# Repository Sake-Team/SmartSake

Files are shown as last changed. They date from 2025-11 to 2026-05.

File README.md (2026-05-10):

# SmartSake

Temperature monitoring and fan control system for koji fermentation, built on a Raspberry Pi 4B.

Reads six MAX31850K thermocouples, an SHT30 humidity sensor, and up to four HX711 load cells. Controls six relay-switched fans to hold temperature curves. Serves a real-time web dashboard over the local network.

<!-- ## Screenshots
Drop PNGs into `images/` and uncomment:
![Dashboard](images/dashboard.png)
![Mobile View](images/mobile.png)
![Curve Builder](images/curves.png)
-->

## About the Project

SmartSake is the controls and instrumentation half of a senior capstone project for the **University of Kentucky Biosystems & Agricultural Engineering** department (BAE 402/403, Fall 2025 – Spring 2026). The mechanical half — the koji table and load cell housings — is documented in `hardware/` and `docs/`.

**Team:** Benjamin Lin, Anastasia Myers, Makenna Hull, Natalie Cupples
**Advisor:** Dr. Alicia Modenbach

For background on the design — problem definition, constraints, alternatives considered, and economic justification — see [`docs/design-report.pdf`](docs/design-report.pdf).

## Safety

This system controls mains-voltage equipment near food-contact surfaces. Before powering anything on:

- **Electrical:** All 120 VAC wiring (relay → fan power) must be enclosed and follow [`docs/schematics/power-schematic.pdf`](docs/schematics/power-schematic.pdf). Do not energize with the relay board exposed. The Pi must be on a separate 5V supply, never tapped from the fan rail.
- **Thermal:** Fans run hot under sustained load. The auto fan-control loop has no upper bound — a misconfigured `tolerance_c` of 0 will keep fans on indefinitely. Always set a sane tolerance (1–2 °C) and check the dashboard during the first hour of every new run.
- **Food contact:** Only the load cell housing surface and the koji table top are food-contact. Use food-safe PETG or food-safe-coated PLA for the [STL parts](hardware/stl/), and sanitize between runs.
- **Crash recovery:** systemd `Restart=on-failure` brings the server back if it dies; the SIGTERM handler drives every fan relay HIGH (= OFF on active-LOW) before exit, so a clean restart leaves no fan stranded on. A hard kill (`SIGKILL`, power loss) bypasses the handler — relays hold their last state.
- **systemd watchdog:** the unit ships with `WatchdogSec=60`; `WriteSensors.py` calls `sd_notify("WATCHDOG=1")` once per sensor tick (~10 s) so a frozen loop is caught and restarted. To temporarily disable the watchdog, drop in `/etc/systemd/system/smartsake.service.d/no-watchdog.conf` with `[Service]\nWatchdogSec=0`, then `systemctl daemon-reload && systemctl restart smartsake`.
- **Hard cutoff:** The dashboard no longer ships an in-page emergency-stop button. To force all fans OFF, kill power at the relay board, or POST to `/api/runs/<id>/emergency-stop` directly (the route still exists server-side).

---

## Daily Operations

The cheat sheet for running SmartSake day-to-day. Detailed background lives in sections 3–4.

### Service control

| Command | Effect |
|---|---|
| `./restart.sh` | Bring up the SmartSake WiFi AP (static IP `192.168.50.1` on `wlan0`, sudo), ensure Tailscale is connected, then restart the server. Default behavior. |
| `./restart.sh --status` | Show whether the server is running |
| `./restart.sh --logs` | Tail the live server log |
| `./restart.sh --ap` | Same as default — explicitly bring up the AP and restart the server (sudo) |
| `./restart.sh --no-ap` | Tear down AP, return to home WiFi (sudo), then restart |
| `./restart.sh --skip-ap` | Restart server without touching network state (use when AP is already up or on dev boxes) |
| `./scripts/ap-mode.sh status` | Report current AP mode without changing anything |
| `sudo systemctl restart smartsake` | Same as `./restart.sh` under systemd |
| `journalctl -u smartsake -f` | Live service journal |

### Where to point the browser

| Mode | URL |
|---|---|
| Home WiFi (normal) | `http://<pi-ip>:8080` — find with `hostname -I` on the Pi |
| AP mode | `http://192.168.50.1:8080` after joining SSID `SmartSake` (default password `kojitable`) |
| Mobile dashboard (any mode) | `<base>/mobile.html` |

### Web pages

| Page | Purpose |
|---|---|
| `/home.html` (default) | New Run, active run resume, previous-runs list, **System Health** card |
| `/dashboard.html?run=<id>&mode=live` | Live monitoring + zone control + bulk setpoint editor |
| `/dashboard.html?run=<id>&mode=replay` | Historical chart playback |
| `/calibration.html` | Probe→zone mapping, TC 2-point cal, load-cell cal (Tare / Calibrate / Calibrate All / Multi-Point / **Apply Manual**) |
| `/curves.html` | Reference temperature curve builder |
| `/mobile.html` | Compact view for phones/tablets |
| `/room-history.html` | Long-window environmental history (lives across runs) |
| `/summary.html?run=<id>` | Per-run digest |
| `/history.html?run=<id>` | Run metadata + tabular detail |

### Starting / running / ending a run

1. **Start** — Home page → enter a run name → optionally pick a reference curve → **Start**. Lands on the live dashboard.
2. **Set targets** — Click **Setpoints / Update** on the dashboard → enter setpoint + tolerance per zone → **Apply All**. Or click any zone to edit one zone's setpoint inline.
3. **Manual fan override** — Open a zone's detail card → segmented pill: `Auto | Off · 1hr | Off | On · 1hr | On`. The 1-hour options auto-revert to Auto.
4. **Notes** — type into the dashboard notes box; saved to localStorage and appended to every CSV row.
5. **End run** — Dashboard **End Run** button. CSV downloads automatically. localStorage cleared (no phantom run on next visit).
6. **Crash recovery** — if the dashboard tab dies mid-run, reopening it silently auto-exports the recovered samples to CSV.

### Calibration (load cells)

1. **Calibrate All (centered load)** — empty the table → **Tare All**. Place a known total weight at the center → enter total kg → **Calibrate All** (splits weight evenly across the 4 cells).
2. **Single cell** — per-row **Tare** (with that cell empty) then **Calibrate** with a known weight on just that cell.
3. **Multi-Point Cal** — open the inline panel for one cell → record zero, then add successive known weights → live raw + computed-kg charts show the fit.
4. **Apply Manual** — type new values directly into the per-row Tare or Factor cells → click **Apply Manual** for that row to nudge without re-loading weights.

### Settings (gear icon, top-right of any page)

- Theme presets (dark, ocean, forest, sakura, etc.)
- **Display Units** — kg/lbs and °C/°F. Flips the dashboard, mobile, room-history, summary, and calibration screens in real time.
- Run Settings (dashboard only) — temperature-deviation thresholds, alert behavior.

### Diagnostics

| Check | How |
|---|---|
| Service alive? | `./restart.sh --status` or look at home page **System Health** card |
| Fan acting weird? | `journalctl -u smartsake -f \| grep '\[fan'` — auto loop logs every transition |
| Sensor errors? | Home page **System Health** → Sensor loop status. Or `cat /run/smartsake/sensor_status.json` |
| Disk getting tight? | Home page **System Health** → Disk free. Threshold warnings start at 100 MB. |
| Multiple "active" runs? | Home page **System Health** → Active runs (should be 0 or 1). The DB now auto-supersedes leftovers on next run start. |
| Smoke-test the fan logic | `python3 test_fan_state.py` — exercises the override / hysteresis / shutdown paths |
| Deeper debug playbook | [`DEBUG.md`](DEBUG.md) — symptom → cause trees for auto fan switching and load cell calibration |

---

## Quickstart

If your Pi is wired and SSH-able:

```bash
git clone https://github.com/Sake-Team/SmartSake.git
cd SmartSake
git checkout ClaudeAgents
sudo bash scripts/onboarding.sh     # Phase 1: install packages, enable overlays
# --- Pi reboots here ---
sudo bash scripts/onboarding.sh     # Phase 2: map thermocouples, calibrate, start service
```

The setup wizard auto-detects which phase to run. After Phase 2, open `http://<pi-ip>:8080` and start a run.

For sensor setup without the full onboarding (e.g., after replacing a probe):

```bash
./setup.sh              # map thermocouples, verify sensors, start service
./setup.sh --remap      # re-run TC identification only
./setup.sh --verify     # check all sensors without starting
./setup.sh --status     # show sensor + service state
```

For manual setup or troubleshooting individual steps, see the full instructions below.

---

## Table of Contents

0. [Daily Operations (cheat sheet)](#daily-operations)
1. [Hardware Setup](#1-hardware-setup)
2. [Software Installation](#2-software-installation)
3. [Running SmartSake](#3-running-smartsake)
4. [Using the Dashboard](#4-using-the-dashboard)
5. [Hardware Files](#5-hardware-files)
6. [Documentation](#6-documentation)
7. [Troubleshooting](#7-troubleshooting)
8. [API Reference](#8-api-reference)
9. [Glossary](#9-glossary)
10. [Contributing](#10-contributing)
11. [License](#11-license)
12. [Acknowledgments](#12-acknowledgments)

---

## 1. Hardware Setup

### Parts List

Quick reference — for the full Bill of Materials with vendors, part numbers, and costs see [`BOM.md`](BOM.md).

| Component | Model | Qty |
|---|---|---|
| Single-board computer | Raspberry Pi 4B | 1 |
| Thermocouple amplifier | MAX31850K (1-Wire) | 6 |
| Humidity/temp sensor | SHT30 (I2C) | 1 |
| Relay board | SunFounder TS0012 (active-LOW, 8-ch) | 1 |
| Load cell amplifier | HX711 | 1-4 |
| Fans | 12V DC (one per zone) | up to 6 |

### GPIO Pin Map (BCM numbering)

```
Pin  2 ── SHT30 SDA (I2C)
Pin  3 ── SHT30 SCL (I2C)
Pin  4 ── 1-Wire data bus (all six MAX31850K)
Pin  5 ── HX711 Scale 1 DAT
Pin  6 ── HX711 Scale 1 CLK
Pin 12 ── HX711 Scale 2 DAT
Pin 15 ── HX711 Scale 2 CLK   (UART RXD0 — disable serial console if used)
Pin 16 ── HX711 Scale 3 DAT
Pin 17 ── Relay CH5 → Fan Zone 5
Pin 19 ── HX711 Scale 3 CLK
Pin 20 ── HX711 Scale 4 DAT
Pin 21 ── HX711 Scale 4 CLK
Pin 22 ── Relay CH4 → Fan Zone 4
Pin 23 ── Relay CH3 → Fan Zone 3
Pin 24 ── Relay CH2 → Fan Zone 2
Pin 25 ── Relay CH1 → Fan Zone 1
Pin 27 ── Relay CH6 → Fan Zone 6
```

> **Reserved pins:** 2/3 (I2C), 4 (1-Wire), 5/6/12/15/16/19/20/21 (HX711). Do not use these for relays.

### Relay Wiring (Active-LOW)

The SunFounder TS0012 is active-LOW:

- **GPIO LOW** = relay coil energized = fan **ON**
- **GPIO HIGH** = relay coil de-energized = fan **OFF**

All relay pins initialize HIGH at boot so fans start OFF.

### 1-Wire Bus (Thermocouples)

All six MAX31850K probes share a single 1-Wire bus on GPIO 4. Each probe has a unique device ID starting with `3b-` and appears at:

```
/sys/bus/w1/devices/3b-XXXXXXXXXXXXX/w1_slave
```

Enable the 1-Wire overlay in `/boot/config.txt`:

```
dtoverlay=w1-gpio,gpiopin=4
```

After wiring, run the probe identification script to assign each physical probe to a zone (1-6):

```bash
python3 scripts/identify_tcs.py
```

This creates `tc_zone_map.json` — the sensor loop will not start until all six zones are mapped.

### SHT30 (I2C)

The SHT30/SHT31 connects to the default I2C bus (pins 2/3). Enable I2C in `raspi-config` if not already on. No additional configuration needed.

### HX711 Load Cells

Scale 1 uses GPIO 5 (DAT) and GPIO 6 (CLK). Scales 2-4 are defined in `scale_config.json` but not wired by default. To calibrate:

```bash
python3 load_cell_hx711.py --calibrate --scale 1
```

To re-tare without full calibration:

```bash
python3 load_cell_hx711.py --tare --scale 1
```

---

## 2. Software Installation

### Prerequisites

```bash
# System packages
sudo apt update
sudo apt install python3 python3-pip git

# Python dependencies
pip3 install flask gunicorn

# Pi hardware libraries
pip3 install RPi.GPIO
pip3 install adafruit-blinka adafruit-circuitpython-sht31d
```

### Clone the Repo

```bash
cd ~
git clone https://github.com/Sake-Team/SmartSake.git
cd SmartSake
git checkout ClaudeAgents
```

### Configuration Files

Three JSON files control hardware mapping. They live in the project root:

**`tc_zone_map.json`** — Thermocouple-to-zone assignment (generated by `scripts/identify_tcs.py`):

```json
{
  "3b-000000000001": 1,
  "3b-000000000002": 2,
  "3b-000000000003": 3,
  "3b-000000000004": 4,
  "3b-000000000005": 5,
  "3b-000000000006": 6
}
```

**`zone_config.json`** — Per-zone temperature tolerance and calibration:

```json
{
  "default": { "tolerance_c": 1.0 },
  "zone1":   { "tolerance_c": 1.0, "setpoint_c": 32.0 },
  "zone2":   { "tolerance_c": 1.5 }
}
```

Optional per-zone fields: `setpoint_c`, `offset_c` (legacy single-point cal), `cal_slope` + `cal_intercept` (two-point cal).

**`scale_config.json`** — Load cell calibration and SHT30 offset:

```json
{
  "sensors": {
    "sht30_temp_offset_c": 0.0
  },
  "scales": {
    "1": {
      "dat_pin": 5,
      "clk_pin": 6,
      "tare_offset": 4166,
      "calibration_factor": 8000,
      "units": "kg",
      "label": "Scale 1"
    }
  }
}
```

### Install systemd Services

For production use on the Pi, install the systemd units so SmartSake starts on boot and auto-restarts on failure:

```bash
sudo bash systemd/install.sh
```

This installs and enables:

| Service | Purpose |
|---|---|
| `smartsake.service` | Flask server + sensor loop (port 8080) |
| `smartsake-sensors.service` | Standalone sensor loop (for multi-worker setups, conflicts with above) |
| `smartsake-backup.timer` | Database backup every 6 hours |

The main service runs as user `kojitable` with resource limits:

- **Memory:** 256 MB max
- **CPU:** 80% quota
- **Watchdog:** 60s (kills hung process)
- **tmpfs:** `/run/smartsake/` for volatile JSON files (protects SD card). Holds `sensor_latest.json`, `fan_state.json`, `sensor_status.json`, and `no_run_overrides.json`.

### Database

SQLite database (`smartsake.db`) is created automatically on first run. No manual setup needed.

---

## 3. Running SmartSake

### Start / Stop / Restart

The canonical way to manage SmartSake is through `restart.sh`, which detects whether systemd is installed and acts accordingly:

```bash
# Start or restart
./restart.sh

# Check status
./restart.sh --status

# Tail live logs
./restart.sh --logs
```

If systemd is installed, these map to:

```bash
sudo systemctl restart smartsake
sudo systemctl status smartsake
journalctl -u smartsake -f
```

If systemd is not installed (development mode), `restart.sh` runs `server.py` directly with `nohup`, logging to `server.log`.

### First Run

1. Wire all hardware and enable 1-Wire + I2C in `raspi-config`
2. Run `python3 scripts/identify_tcs.py` to create `tc_zone_map.json`
3. Run `python3 load_cell_hx711.py --calibrate --scale 1` (if using a scale)
4. Install services: `sudo bash systemd/install.sh`
5. Open `http://<pi-ip>:8080` in a browser

### Stopping the Server

```bash
# With systemd
sudo systemctl stop smartsake

# Without systemd (dev mode)
pkill -f "python.*server.py"
```

### Updating

Pull the latest code and restart:

```bash
cd ~/SmartSake
git pull
./restart.sh
```

### Standalone WiFi Access Point Mode

The Pi self-hosts a local LAN. `./restart.sh` brings the SmartSake WiFi AP
up by default (no flag needed) on `wlan0` with the static IP defined in
`scripts/ap-config.env` (`192.168.50.1` by default). Mobile devices join
SSID `SmartSake` and reach the dashboard at `http://192.168.50.1:8080`.

```bash
# Default: bring up the AP, assign 192.168.50.1, then start the server
sudo ./restart.sh

# Explicit alias of the default
sudo ./restart.sh --ap

# Tear down the AP, return to home WiFi, restart the server
sudo ./restart.sh --no-ap

# Restart the server WITHOUT touching network state (server only)
./restart.sh --skip-ap

# Or call the helper directly
sudo ./scripts/ap-mode.sh start
sudo ./scripts/ap-mode.sh stop
./scripts/ap-mode.sh status
```

Defaults: SSID `SmartSake`, password `kojitable`, **static IP `192.168.50.1`**,
DHCP pool `192.168.50.50`–`.150`. Edit `scripts/ap-config.env` to change. The
static IP is reapplied on every `./restart.sh` via `ip addr add` against
`wlan0`, so the Pi is always reachable at the same address while the AP is up.

**Prerequisites:** `sudo apt install hostapd dnsmasq`.

**Best-effort start:** if `restart.sh` runs on a box with no `wlan0`, no sudo,
or missing `hostapd`/`dnsmasq`, the AP step warns and is skipped — the server
still starts. Use `--skip-ap` to suppress the attempt entirely on dev boxes.

**Reversibility:** `--no-ap` removes the AP configs (`/etc/hostapd/smartsake.conf`,
`/etc/dnsmasq.d/smartsake-ap.conf`), restarts NetworkManager / wpa_supplicant,
and the Pi reconnects to home WiFi.

**Recommendation for first try:** keep a wired ethernet cable connected so SSH
remains reachable if anything goes sideways.

### Remote access via Tailscale

The Pi runs `tailscaled` as an enabled systemd service, so it auto-starts on
boot and reconnects automatically to the tailnet (no flag, no login required
after the initial `tailscale up`). On every `./restart.sh` an idempotent
`ensure_tailscale_up` step verifies the connection: if `tailscale ip -4`
already returns an address it's a no-op, otherwise it runs `sudo tailscale up`.
A missing binary or auth failure is warned and does not abort the script.

```bash
# Initial one-time auth (prints a URL to open in a browser)
sudo tailscale up

# Verify
tailscale status
tailscale ip -4
```

Once authenticated, this Pi is reachable from any other tailnet device by its
tailnet IP (or MagicDNS hostname) — useful for working off-site without
exposing port 8080 to the public internet. Install Tailscale on your laptop,
sign in to the same account, then `ssh kojitable@<tailnet-ip>` or browse to
`http://<tailnet-ip>:8080`.

### Development Mode (Windows/Mac)

A mock server is included for UI development without Pi hardware:

```bash
pip install flask
python archive/mock_server.py
# Opens at http://localhost:8080 with simulated sensor data
```

The mock serves the real HTML/CSS/JS from the project root and stubs every API
endpoint the dashboard, calibration page, curves page, and zone pages call —
including `/api/sensor-status`, `/api/tc-probes`, `/api/tc-zone-map`,
`/api/tc-calibration/<zone>/...`, `/api/scale-config[/<id>/...]`,
`/api/runs/<id>/summary`, `/api/reference-curves/generate[-from-csv]`,
`/api/runs/<id>/emergency-stop`, `/api/fans/<zone>`, and `/api/prune`.

All hardware imports degrade gracefully — `RPi.GPIO`, `adafruit_sht31d`, and HX711 log warnings and run as no-ops when unavailable.

---

## 4. Using the Dashboard

### Accessing SmartSake

Once running, open a browser to:

```
http://<pi-ip-address>:8080
```

Find the Pi's IP with `hostname -I` on the Pi, or check your router's device list.

### Pages

| Page | URL | Purpose |
|---|---|---|
| Home | `/` | Start/resume runs, view history |
| Dashboard | `/dashboard.html?run=N&mode=live` | Real-time temp, fan, and weight monitoring |
| Mobile | `/mobile.html` | Lightweight phone/tablet view |
| Calibration | `/calibration.html` | TC offset and load cell calibration |
| Curve Builder | `/curves.html` | Create/edit temperature reference curves |
| History | `/history.html?run=N` | Detailed run data table |
| Summary | `/summary.html?run=N` | Hourly temperature statistics |
| Room History | `/room-history.html` | Ambient environment over time |

### Home Page

The landing page shows:

- **Active run** — if a batch is in progress, with a "Resume" button to jump to the live dashboard
- **New Run** — name a batch and optionally attach a reference temperature curve
- **Tools** — links to Curve Builder, Calibration, Room History, and Mobile View
- **System Health** — at-a-glance Pi status: active-runs count (should be 0–1; >1 surfaces a leak), sensor-loop status, last sample age, free disk, and any active fan overrides (in-run + no-run with mode and time-to-expiry). Polls `/api/system-health` every 15 s while the tab is visible; pauses when hidden.
- **Previous Runs** — all completed/crashed batches with View, Summary, Details, Lock, and Delete actions

### Dashboard (TV / Desktop)

The main dashboard is designed for a wall-mounted display. It shows:

- **Six zone cards** — current temperature, fan state (ON/OFF badge), and deviation from target
- **Temperature chart** — live line graph updated every 10 seconds
- **Fan state indicators** — mode (limit/manual/rule), setpoint, trigger point, alarm level
- **Weight chart** — load cell readings updated every 30 seconds
- **Humidity/ambient** — SHT30 environment readings
- **Zone controls** — click any zone card to open fan overrides, rules, notes, and calibration
- **Update Setpoints card** — opens a blanket-only modal: enter one setpoint and/or one tolerance, click Apply, and the values are written to every zone in a single atomic POST to `/api/zone-config/all` (RLock-guarded on the server). Per-zone edits live on each zone card's existing detail modal
- **Display units** — open the gear (Settings) modal to switch weight between **lbs / kg** and temperature between **°C / °F**. Both preferences persist in `localStorage` (`sakeWeightUnit`, `sakeTempUnit`); changes apply live to every dashboard chart, stat card, zone card, and zone-detail modal — and propagate (via the `sake-units-changed` event plus a cross-tab `storage` listener) to **`mobile.html`**, **`room-history.html`**, and **`summary.html`**. Internally the backend always stores Celsius — `°F` inputs are converted on send (and tolerance, being a delta, is divided by `9/5`).

**Fan control modes:**

| Mode | How it works |
|---|---|
| Auto (limit) | Fans turn on when temp exceeds setpoint + tolerance, off when temp drops below setpoint |
| On / Off (untimed) | Force a zone's fan ON or OFF until you press Auto. Persists across service restarts (cleared on full reboot). |
| On · 1hr / Off · 1hr | Same as above but auto-expires after 60 minutes, returning the zone to Auto. |
| Rules | Time-window or threshold-based triggers (configured per-run) |

**Override persistence:**

- **Active run:** overrides live in the SQLite `fan_overrides` table — survive any restart, expire on `expires_at`.
- **No active run:** overrides live in `/run/smartsake/no_run_overrides.json` (volatile dir) — survive `smartsake.service` restarts (watchdog, deploys, crashes), but cleared on a full reboot for safety.
- Starting a new run wipes any no-run overrides (the run owns its own override table).

### Mobile Dashboard (iPhone / iPad)

Navigate to `/mobile.html` or tap "Mobile View" from the home page.

Optimized for phones (375px and up):

- **2-column grid** of zone cards with large temperature numbers
- **Fan ON/OFF badges** per zone (green/gray)
- **Alarm states** — amber border for warnings, pulsing red for critical deviations
- **Environment bar** — humidity and ambient temp
- **Weight summary** — shown when a scale is active
- **Connection-lost banner** — appears after 3 failed fetches
- **Stale-data indicator** — timestamp turns amber if data is older than 60 seconds

The mobile page is read-only (monitoring only). For fan overrides and zone configuration, use the full dashboard.

To add SmartSake to your iPhone home screen as an app:

1. Open `http://<pi-ip>:8080/mobile.html` in Safari
2. Tap the Share button → "Add to Home Screen"
3. It will launch full-screen without Safari's address bar

### Calibration Page

`/calibration.html` (linked from the home page) covers thermocouple offsets, probe-to-zone mapping, and load cell calibration. The thermocouple workflows (`2-Point Cal`, `Quick Cal`) and the probe mapping panel are documented inline on the page.

#### Probe → Zone Heat-Detect (web equivalent of `identify_tcs.py`)

The **Probe → Zone Mapping** panel now mirrors the CLI's heat-and-identify flow so the mapping can be (re)built without dropping to a shell:

1. Pick the zone you want to identify from the **Detect zone** dropdown.
2. Click **Capture Baseline** — the current temperature of every probe on the 1-Wire bus is snapshotted; the **Δ since baseline** column resets to `+0.00`.
3. Physically heat the probe you want for that zone (skin contact, hot-water bath, etc.) for ~15 s. The Δ column updates every poll (~3 s); rows that climb ≥ 2 °C above baseline are highlighted in green.
4. Click **Detect (after heating)** — the probe with the largest rise (excluding probes already manually assigned to other zones) is auto-assigned to the chosen zone, and the Detect dropdown advances to the next unassigned zone.
5. Repeat for each remaining zone, then click **Save Mapping**. The mapping is persisted to `tc_zone_map.json` and the sensor loop picks it up within ~10 s.

The 2 °C rise threshold mirrors `RISE_THRESHOLD_C` in `scripts/identify_tcs.py`. Below-threshold detections are rejected with a status message ("heat longer and click Detect again") rather than silently misassigning. **Clear Baseline** discards the snapshot if you want to redo the protocol. Manual dropdown selections are preserved across the 3-second poll — the table now diff-renders, so in-progress edits aren't wiped before you save.

#### Calibrate All (Centered Load)

Above the per-scale table, a **Calibrate All (centered load)** panel handles all 4 cells in two clicks. Step 1: empty the table and click **Tare All** — every wired scale tares in parallel. Step 2: place a known weight at the **center** of the table, enter the **total mass in kg**, and click **Calibrate All**. The total is divided equally across the wired cells (`total / 4`, or `total / N` if fewer than 4 are wired) and pushed to each scale's `known_weight_kg`. Unwired scales are skipped automatically. The per-scale Tare / Calibrate / Multi-Point Cal buttons in the table below remain available for individual cells.

#### Multi-Point Cal (Load Cells)

For higher accuracy across a wide load range (e.g. 0–9 kg of rice), use the **Multi-Point Cal** workflow on the calibration page:

1. Open `/calibration.html` and find the scale row in the **Load Cells** panel.
2. Click **Multi-Point Cal** — an inline panel expands below the row.
3. **Step 1 — Record Zero**: place the table and any fixed load you want zeroed (housings, lids, empty trays). Click **Record Zero (with table loaded)**. The current raw reading is declared as `0 g`. You don't need to know the mass of the fixture.
4. **Step 2+ — Add Known Weight**: place a known mass on the scale, type its weight in grams (or click a rice-bag preset: 2000 g / 4000 g / 5000 g / 9000 g), optionally add a label, then click **Record Point**. Repeat for as many reference weights as you want — the more spread, the better the fit.
5. The recorded points table shows each point's label, weight, raw ADC reading, and delta from the previous raw. Use **Remove** to drop a single point, or **Clear All Points** to start over.
6. Two side-by-side live charts update once a second while the panel is open:
   - **Left (Raw ADC)**: rolling 60-sample window of the raw integer reading. Useful for spotting noise, drift, or wiring issues.
   - **Right (Computed weight, kg)**: the same window converted to kg using the **currently saved** calibration. Horizontal dashed reference lines mark each recorded `weight_g / 1000`, so you can see how close the live reading lands to each known point.
7. Below the right chart, a **residuals readout** shows, for each recorded point, the live error in grams (`live reads X g, error ±Y g`).
8. Click **Done** to close the panel — the fast 1 s polling loop is torn down automatically (and also pauses when the browser tab is hidden).

The backend auto-derives `tare_offset` and `calibration_factor` from the min-weight and max-weight points whenever 2 or more points are present, so the running scale picks up the multi-point cal immediately — no service restart needed. The single-point **Tare** and **Calibrate** buttons remain available as a quick-cal alternative.

### Polling Intervals

| Data | Backend interval | Frontend poll |
|---|---|---|
| Temperature (TC) | 10s | 10s |
| Humidity (SHT30) | 10s | 10s |
| Fan relay control | 10s | 10s |
| Weight (HX711) | 30s | 30s |
| Stage markers | on change | 30s |

Front-end pollers (`fetchAndApply`, `fetchFanState`) carry an in-flight reentrancy guard, so a slow Pi will skip a tick instead of stacking parallel requests.

### Accessibility

The dashboard is the primary operator surface and aims for WCAG 2.1 AA on the controls that matter most for safe operation:

- All icon-only buttons (settings gear, elapsed/clock toggle) have explicit `aria-label`s.
- The fan-mode segmented control is a `role="group"` with `aria-pressed` mirroring the visual `--active` state, so screen readers announce the current selection.
- The connection-lost banner is an `role="alert" aria-live="assertive"` region; sensor poll failures are announced.
- All four metric canvases (temperature, humidity, fans, weight) have descriptive `aria-label`s.
- Keyboard focus on every primary control surface (fan-mode segments, time-window buttons, settings) shows a 2 px outline via `:focus-visible` — outlines are painted outside the box, so layout doesn't shift.
- `prefers-reduced-motion: reduce` disables transitions on interactive controls.

---

## File Structure

```
SmartSake/
├── server.py              # Flask API server (starts sensor loop as background thread)
├── WriteSensors.py        # Sensor collection loop (standalone or via server.py)
├── db.py                  # SQLite database layer
├── fan_gpio.py            # GPIO relay abstraction
├── sensors.py             # 1-Wire and SHT30 helpers
├── load_cell_hx711.py     # HX711 ADC driver and calibration CLI
├── home.html              # Landing page
├── dashboard.html         # Main monitoring dashboard
├── dashboard-phase2.js    # Stage markers + weight analytics overlay
├── mobile.html            # Mobile-optimized dashboard
├── calibration.html       # TC and scale calibration UI
├── curves.html            # Reference curve builder
├── history.html           # Run detail table
├── summary.html           # Hourly stats for completed runs
├── room-history.html      # Ambient environment history
├── styles.css             # Shared theme and component styles
├── customize.js           # Theme customization (light/dark)
├── restart.sh             # Start/restart/status/logs helper
├── requirements.txt       # Python dependencies
├── tc_zone_map.json       # Probe-to-zone mapping (generated)
├── zone_config.json       # Per-zone tolerance and calibration
├── scale_config.json      # Load cell config and SHT30 offset
├── smartsake.db           # SQLite database (auto-created)
├── sensor_data.csv        # Rolling CSV log (~24 hrs)
├── archive/
│   └── mock_server.py    # Local UI preview server (no Pi required)
├── scripts/
│   └── identify_tcs.py    # Interactive probe identification
├── systemd/
│   ├── smartsake.service          # Main service unit
│   ├── smartsake-sensors.service  # Standalone sensor unit
│   ├── smartsake-backup.service   # DB backup (oneshot)
│   ├── smartsake-backup.timer     # Backup schedule (every 6h)
│   └── install.sh                 # Service installer
├── images/
│   └── VoidSakeLogo.jpg   # Logo
├── hardware/
│   ├── bill-of-materials.xlsx
│   ├── cad/
│   │   ├── sake-table-drawing.pdf
│   │   ├── sake-table-exploded.png
│   │   └── load-cell-housing-drawing.pdf
│   └── stl/
│       ├── load-cell-housing.stl
│       └── load-cell-housing-lid.stl
└── docs/
    ├── design-report.pdf
    ├── standards-memo.pdf
    ├── brewing-flow-chart.png
    └── schematics/
        ├── koji-room-layout.png
        ├── power-schematic.pdf
        ├── wiring-schematic.pdf
        ├── signal-schematic.svg
        └── smartsake-wiring.json   # EasyEDA source (LV signal + 120 V power, 2 sheets)
```

---

## 5. Hardware Files

### Bill of Materials

[`hardware/bill-of-materials.xlsx`](hardware/bill-of-materials.xlsx) — full parts list with vendors, part numbers, quantities, and unit costs (Spring 2026 revision).

### CAD Drawings

| File | Description |
|---|---|
| [`hardware/cad/sake-table-drawing.pdf`](hardware/cad/sake-table-drawing.pdf) | Dimensioned drawing of the koji table (v3) |
| [`hardware/cad/sake-table-exploded.png`](hardware/cad/sake-table-exploded.png) | Exploded assembly view |
| [`hardware/cad/load-cell-housing-drawing.pdf`](hardware/cad/load-cell-housing-drawing.pdf) | Load cell housing dimensioned drawing |

### 3D-Printable Parts (STL)

| File | Description | Notes |
|---|---|---|
| [`hardware/stl/load-cell-housing.stl`](hardware/stl/load-cell-housing.stl) | Load cell housing body (v3) | PLA or PETG, 0.2mm layer, 30% infill |
| [`hardware/stl/load-cell-housing-lid.stl`](hardware/stl/load-cell-housing-lid.stl) | Load cell housing lid | Same settings as body |

The native Fusion 360 file (`SakeTableCAD.f3z`) is not included due to size; contact the team if you need the editable source.

---

## 6. Documentation

| File | Description |
|---|---|
| [`docs/design-report.pdf`](docs/design-report.pdf) | Full design report — problem, alternatives, final design, economic justification |
| [`docs/standards-memo.pdf`](docs/standards-memo.pdf) | Applicable engineering standards (food safety, electrical, fabrication) |
| [`docs/brewing-flow-chart.png`](docs/brewing-flow-chart.png) | Sake brewing process flow chart |
| [`docs/schematics/koji-room-layout.png`](docs/schematics/koji-room-layout.png) | Koji room physical layout |
| [`docs/schematics/power-schematic.pdf`](docs/schematics/power-schematic.pdf) | Power distribution schematic |
| [`docs/schematics/wiring-schematic.pdf`](docs/schematics/wiring-schematic.pdf) | Full wiring schematic (Pi → relays → fans → sensors) |
| [`docs/schematics/signal-schematic.svg`](docs/schematics/signal-schematic.svg) | Signal-level schematic (1-Wire, I2C, GPIO) |
| [`docs/schematics/smartsake-wiring.json`](docs/schematics/smartsake-wiring.json) | Editable EasyEDA source — Sheet 1: LV signal wiring (Pi GPIO → MAX31850K × 6, SHT30, HX711 × 4, relay logic). Sheet 2: 120 VAC power wiring (separate Pi-supply outlet, relay-switched fans, always-on dehumidifier). Open in EasyEDA Std Edition via *File → Open → Local*. |

---

## 7. Troubleshooting

### Stability tests
All standalone — no pytest, no hardware required. Each prints PASS/FAIL with a coloured summary and exits non-zero if anything fails. Run individually:

- `python3 test_fan_state.py` — fan state machine: mocks `db` + `fan_gpio`, exercises override/hysteresis/run-transition paths.
- `python3 test_config_robustness.py` — JSON config loaders (`zone_config.json`, `scale_config.json`, `tc_zone_map.json`, `no_run_overrides.json`, and `server._read_json_cached`) under empty/truncated/trailing-comma/non-UTF8/wrong-type/extreme-value inputs. Verifies graceful degradation.
- `python3 test_db_safety.py` — SQLite layer: fresh init, idempotent re-init, `PRAGMA integrity_check` on corruption, `create_run` superseding leftover active runs, `end_run` closing open deviation events, schema migration paths, and threadlocal connection isolation. Uses temp DBs via `tempfile.NamedTemporaryFile` — never touches `smartsake.db`.
- `python3 test_input_fuzz.py` — Flask API endpoints (test_client, no port binding): empty bodies, malformed JSON, wrong types, extreme numerics (Infinity / NaN / 1e300), unicode, oversize strings, bogus path params. Verifies 4xx not 5xx.
- `python3 test_failure_injection.py` — failure-injection: monkey-patches `set_fan`, `insert_reading`, `read_temp_c`, `HX711.get_weight`, `read_sht30`, `_load_zone_config`, `_persist_no_run_overrides`, etc. to raise mid-tick. Verifies the sensor loop, fan-eval, HX711 thread, and watchdog all degrade gracefully (log + continue) rather than crashing.
- `python3 test_concurrency.py` — threading/race stress: mtime-cached config readers (`scale_config.json`, `zone_config.json`, server's `_read_json_cached`), SQLite thread-local pool isolation under 8×100 concurrent inserts, `_no_run_overrides_lock` set/clear/purge/expiry hammer, fan-state atomic-write rename safety, and concurrent `_write_scale_cfg` (Calibrate-All) lost-update detection. Mocks `RPi.GPIO`, uses `tempfile` so it never touches real config or `smartsake.db`.

### Dashboard won't load / can't reach Pi
- `ping <pi-ip>` — confirm the Pi is on the network
- On the Pi: `sudo ss -tlnp | grep 8080` — confirm something is listening
- `sudo systemctl status smartsake` — check for crash loops
- If the port is taken by a stale process: `pkill -f "python.*server.py"` then `./restart.sh`

### "Sensor loop will not start — tc_zone_map.json incomplete"
All six probes must be mapped before the loop runs. There is no auto-assignment.
```bash
python3 scripts/identify_tcs.py            # interactive — heat each probe in turn
python3 scripts/identify_tcs.py --check    # validate (no dupes, all 6 present)
sudo systemctl restart smartsake
```

### Probe shows N/A or wild jumps
- Check the 1-Wire bus on GPIO 4 — `ls /sys/bus/w1/devices/` should list six `3b-…` entries
- Loose probe wiring is the most common cause; reseat at the screw terminal
- Live monitor without writes: `python3 scripts/identify_tcs.py --monitor`

### Fan stuck ON or OFF
1. Check the dashboard zone card for an active manual override or rule — clear it
2. Verify relay logic is active-LOW (GPIO LOW = fan ON) — see `fan_gpio.py`
3. If a relay is mechanically stuck, hard-cycle the relay board's 5V supply
4. Hit `POST /api/runs/<id>/emergency-stop` (e.g. `curl -X POST http://<pi>:8080/api/runs/$RUN/emergency-stop`) — or pull power at the relay board — to force all fans OFF, then diagnose

### Fan stays ON after clicking Auto
Clearing a manual ON override now also resets the auto-loop hysteresis (`_fan_on=False`, `_fan_hold_counts=0`) so the next auto evaluation starts from a fresh "fan off" baseline. Previously the fan could stay on indefinitely if the actual temp was inside the deadband (setpoint < actual ≤ trigger) because hysteresis preserved the manual ON state. Auto now re-evaluates fresh and only turns the fan back on when actual truly exceeds the trigger. Same behavior applies when a timed override expires naturally.

### Scale reads zero or drifts
- Re-tare without recalibrating: `python3 load_cell_hx711.py --tare --scale N`
- Full calibration with a known weight: `python3 load_cell_hx711.py --calibrate --scale N`
- Confirm DAT/CLK pins in `scale_config.json` match the wiring (defaults: 5/6 for scale 1)
- HX711 is sensitive to vibration and temperature swings; mount it rigidly

### "Database is locked"
Another process is writing. Stop everything and restart cleanly:
```bash
sudo systemctl stop smartsake smartsake-sensors
sudo systemctl start smartsake
```
The `-sensors` standalone unit conflicts with the main service — only one of them should be active.

### Hot-reload not picking up config changes
The server uses an mtime check. If you edit `zone_config.json` over SMB or with an editor that writes atomically (replacing the file), mtime updates correctly. If you `cat >` the file, mtime may not change — `touch zone_config.json` to force.

---

## 8. API Reference

All endpoints are JSON unless noted. Base URL is `http://<pi-ip>:8080`.

### Health & status
| Method | Path | Purpose |
|---|---|---|
| GET | `/api/health` | Overall system health (sensor loop, DB, GPIO) |
| GET | `/api/system-health` | Aggregator for the home-page System Health card. Returns `{active_runs, sensor_status, last_sample_age_s, disk_free_mb, overrides[]}`. 5 s server-side cache. `sensor_status.status` is `"unknown"` when `/run/smartsake/sensor_status.json` does not yet exist (e.g. fresh boot before the sensor loop has written status), so callers can distinguish "loop never reported" from "loop says ok". |
| GET | `/api/sensor-status` | Sensor loop diagnostics, library availability, last-write age |
| GET | `/api/latest` | Latest TC + SHT30 + weight reading |
| GET | `/api/fan-state` | Latest fan state per zone (mode, setpoint, alarm) |

### Runs
| Method | Path | Purpose |
|---|---|---|
| GET | `/api/runs` | List all runs |
| GET | `/api/runs/active` | Currently active run (if any) |
| POST | `/api/runs` | Start a new run — body: `{name, target_curve_id?}` |
| GET | `/api/runs/<id>` | Get run metadata |
| POST | `/api/runs/<id>/end` | Mark run completed |
| DELETE | `/api/runs/<id>` | Delete run (unless locked) |
| POST | `/api/runs/<id>/pin` | Lock/unlock run from deletion |
| POST | `/api/prune` | Free disk by deleting oldest unlocked runs |
| GET | `/api/runs/<id>/readings` | Full reading history |
| GET | `/api/runs/<id>/latest` | Latest reading for this run |
| GET | `/api/runs/<id>/summary` | Hourly temp stats per zone |
| GET | `/api/runs/<id>/export.csv` | Stream all readings as CSV |
| GET | `/api/runs/completed` | List completed runs |
| GET | `/api/room-history?hours=N` | Ambient SHT30 history |

### Targets, fans, zones
| Method | Path | Purpose |
|---|---|---|
| GET / POST | `/api/runs/<id>/target` | Get/set per-run reference temperature curve |
| POST | `/api/runs/<id>/target/from-curve/<curve_id>` | Load a saved curve as the target |
| GET | `/api/runs/<id>/zones` | All per-zone notes |
| GET / PUT | `/api/runs/<id>/zones/<n>` | Get/save zone note |
| GET | `/api/runs/<id>/fan-overrides` | Active manual overrides |
| POST / DELETE | `/api/runs/<id>/zones/<n>/fan` | Set/clear manual override on zone N. POST body: `{"action":"on"\|"off","duration_minutes":<int 1-10080>\|null}` (cap = 7 days). |
| POST | `/api/fans/<n>` | No-run direct fan control. Body: `{"action":"on"\|"off"\|"auto","duration_minutes":<int 1-10080>\|null}`. Persists in `/run/smartsake/no_run_overrides.json`. |
| POST | `/api/runs/<id>/emergency-stop` | Force all six zones OFF |
| GET / POST | `/api/runs/<id>/fan-rules` | List/create rule-based triggers |
| PATCH / DELETE | `/api/runs/<id>/fan-rules/<rule_id>` | Toggle/delete rule |
| GET | `/api/runs/<id>/deviations` | All deviation events |
| GET | `/api/runs/<id>/deviations/active` | Currently-active deviations |

### Reference curves
| Method | Path | Purpose |
|---|---|---|
| GET / POST | `/api/reference-curves` | List/save curves |
| GET / DELETE | `/api/reference-curves/<id>` | Get/delete curve |
| POST | `/api/reference-curves/generate` | Build a curve from completed runs — body: `{run_ids, bucket_min}` where `bucket_min` is the build interval in minutes (0.6–360, the curves UI exposes this as **0.01–6 hr at 0.01-h precision**) |
| POST | `/api/reference-curves/generate-from-csv` | Build a curve from a CSV upload — same `bucket_min` semantics (multipart `bucket_min` field or JSON `{csv_text, bucket_min}`) |

### Calibration & config
| Method | Path | Purpose |
|---|---|---|
| GET / POST | `/api/zone-config` | Read/write `zone_config.json` (per-zone deep merge, RLock-guarded) |
| POST | `/api/zone-config/all` | Blanket update — one `{setpoint_c, tolerance_c}` written to every zone 1–6 in a single atomic file write |
| GET | `/api/scale-config` | Read `scale_config.json` |
| POST | `/api/tc-calibration/<zone>` | Set per-zone TC offset directly |
| GET | `/api/scale-config/<id>/calibration-points` | List multi-point calibration points for a scale |
| POST | `/api/scale-config/<id>/record-cal-point` | Record one calibration point (`{weight_g, label?}`) at the current raw reading; auto-derives tare + factor from min/max-weight points |
| DELETE | `/api/scale-config/<id>/calibration-points` | Clear all multi-point calibration points for a scale |

Most write endpoints validate input (range checks on `tolerance_c`, `setpoint_c`, `offset_c`) and return `400` with an `error` key on failure. See `server.py` for exact validation rules.

---

## 9. Glossary

For readers without a brewing background:

| Term | Meaning |
|---|---|
| **Sake** | Japanese alcoholic beverage made by fermenting rice; requires koji to convert rice starches to sugars before yeast fermentation |
| **Koji** (麹) | Steamed rice inoculated with *Aspergillus oryzae* mold; produces enzymes that convert starch to sugar |
| **Kojikin** (麹菌) | The *A. oryzae* spores themselves, sprinkled onto cooled steamed rice to start a koji batch |
| **Koji-muro** | Traditional koji-making room — warm, humid, temperature-controlled. SmartSake automates this. |
| **Koji table** | The wooden/stainless table inside the koji-muro where rice ferments. Our table has six independently-controlled fan zones. |
| **Moromi** | The main fermentation mash — koji + steamed rice + yeast + water. Happens after koji is finished. |
| **Tane-kōji** | The "seed koji" — a previous batch of koji used to inoculate a new batch (alternative to dried kojikin) |
| **Zone** | One of the six independently-monitored regions of the koji table, each with its own thermocouple and fan |
| **Setpoint** | Target temperature for a zone, in °C |
| **Tolerance** | How far above setpoint the temp must go before the fan kicks on (typically 1–2 °C) |
| **Reference curve** | A planned temperature schedule over a 24–48 hr koji run; the dashboard plots actual vs. reference |

---

## 10. Contributing

This is an active capstone project. If you are on the team:

1. Work on the `ClaudeAgents` branch — `main` and `zany` are protected
2. Update [`README.md`](README.md) whenever you change wiring, GPIO assignments, config schemas, scripts, or systemd units (see [`CLAUDE.md`](CLAUDE.md) for the full rule set)
3. Hardware imports (`RPi.GPIO`, `adafruit_sht31d`, HX711) must degrade gracefully so the code still imports on a dev laptop — wrap in try/except and log a warning
4. Run the mock server locally before pushing changes that touch the dashboard:
   ```bash
   python archive/mock_server.py
   ```

For external contributors: please open an issue describing the change before submitting a PR.

---

## 11. License

This project is released for academic and educational use. Hardware designs (CAD, STL, schematics) and software are © 2025–2026 the SmartSake team. Reuse for non-commercial purposes is permitted with attribution. Contact the team for commercial licensing.

---

## 12. Acknowledgments

- **Dr. Alicia Modenbach** — capstone advisor, BAE Department
- **University of Kentucky Biosystems & Agricultural Engineering** — capstone program, lab space, fabrication resources
- **Open-source projects:** Flask, Adafruit CircuitPython libraries, Chart.js, the HX711 driver community
- **The brewing community** — for centuries of documented technique that made the temperature curves possible

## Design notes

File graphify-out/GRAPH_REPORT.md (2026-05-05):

# Graph Report - .  (2026-05-02)

## Corpus Check
- Corpus is ~25,976 words - fits in a single context window. You may not need a graph.

## Summary
- 503 nodes · 708 edges · 20 communities detected
- Extraction: 94% EXTRACTED · 6% INFERRED · 0% AMBIGUOUS · INFERRED: 43 edges (avg confidence: 0.67)
- Token cost: 0 input · 0 output

## God Nodes (most connected - your core abstractions)
1. `get_conn()` - 52 edges
2. `HX711` - 33 edges
3. `start_sensor_loop()` - 16 edges
4. `_init()` - 11 edges
5. `server.py â€” Flask API Server` - 10 edges
6. `Historian` - 9 edges
7. `_record()` - 8 edges
8. `evaluate_fan_state()` - 8 edges
9. `Diagnostics Commands (CONTROLS)` - 8 edges
10. `_read_json_cached()` - 8 edges

## Surprising Connections (you probably didn't know these)
- `SmartSake` --references--> `VoidSake Logo`  [INFERRED]
  README.md → images/VoidSakeLogo.jpg
- `HX711` --uses--> `Return {zone: [(elapsed_min, temp_target)]} — one shared curve for all zones.`  [INFERRED]
  C:\Users\benja\Assistant\SmartSake\load_cell_hx711.py → C:\Users\benja\Assistant\SmartSake\WriteSensors.py
- `HX711` --uses--> `Linearly interpolate target temp at elapsed_min. Clamps at edges.`  [INFERRED]
  C:\Users\benja\Assistant\SmartSake\load_cell_hx711.py → C:\Users\benja\Assistant\SmartSake\WriteSensors.py
- `HX711` --uses--> `Load zone_config.json, reloading automatically when the file changes.`  [INFERRED]
  C:\Users\benja\Assistant\SmartSake\load_cell_hx711.py → C:\Users\benja\Assistant\SmartSake\WriteSensors.py
- `HX711` --uses--> `Return {zone: 'on'|'off'|None} based on overrides, rules, then limit-switch.`  [INFERRED]
  C:\Users\benja\Assistant\SmartSake\load_cell_hx711.py → C:\Users\benja\Assistant\SmartSake\WriteSensors.py

## Communities

### Community 0 - "Database Layer"
Cohesion: 0.03
Nodes (103): _bucket_average_one_source(), clear_fan_override(), close_conn(), close_deviation_event(), _combine_buckets(), compute_pearson_r(), create_deviation_event(), create_fan_rule() (+95 more)

### Community 1 - "Flask API Routes"
Cohesion: 0.03
Nodes (48): api_calibrate_tc_from_reference(), api_calibrate_tc_two_point(), api_emergency_stop(), api_fan_state(), api_generate_curve_from_csv(), api_get_scale_config(), api_get_zone_config(), api_health() (+40 more)

### Community 2 - "HX711 Scale Driver"
Cohesion: 0.05
Nodes (55): Exception, calibrate(), HX711, load_scale_config(), log_weight(), Read weight. Returns (weight_value, raw_avg) — one read batch, two outputs., Load scale_config.json and return {scale_id: HX711_instance} for configured scal, Write current weight to JSON for main system integration. (+47 more)

### Community 3 - "Server Endpoints"
Cohesion: 0.03
Nodes (16): api_fan_state(), api_latest(), _build_sensor_payload(), _fake_readings(), _fake_temp(), _koji_curve(), _now(), _oscillating_temp() (+8 more)

### Community 4 - "Project Config & Rules"
Cohesion: 0.06
Nodes (41): Active-LOW Relay Convention (CLAUDE.md), Branch Rules (ClaudeAgents Active), Config Hot-Reload by Mtime Rationale, README Maintenance Rule, GET /api/health Endpoint, calibrate_sht30.py â€” SHT30 Calibration Script, calibrate_sht30.py Script, Calibration Procedures (CONTROLS) (+33 more)

### Community 5 - "Backup & Code Standards"
Cohesion: 0.08
Nodes (31): Coding Standards, Code Generation Delegation Rationale, Graceful Hardware Degradation Rationale, backup_db.py â€” Database Backup Script, backup_db.py Manual Backup Script, Database Backup Procedure, Database Backup (Daily 2AM + Manual), SmartSake GitHub Repo (ClaudeAgents branch) (+23 more)

### Community 6 - "TC Probe Identification"
Cohesion: 0.1
Nodes (21): cmd_assign(), cmd_check(), cmd_monitor(), main(), Return {device_id: temp_c or None} for every device on the bus., _read_all(), Diagnostic tool for MAX31850K thermocouples + SHT30. Imports shared sensor help, Append a row of thermocouple readings to the CSV log. (+13 more)

### Community 7 - "Dashboard Phase 2"
Cohesion: 0.15
Nodes (13): _buildBandPlugin(), _buildToolbar(), _init(), _loadMarkers(), _loadTargets(), _poll(), _populateSelector(), _registerPlugin() (+5 more)

### Community 8 - "Historian Archive"
Cohesion: 0.24
Nodes (2): Historian, Historian module for Raspberry Pi sake fermentation monitoring. Provides SQLite

### Community 9 - "Theme Customization"
Cohesion: 0.42
Nodes (9): applyTheme(), buildCustomVars(), buildModal(), buildSwatchHTML(), closeModal(), init(), openModal(), shadeColor() (+1 more)

### Community 10 - "Hardware Test Suite"
Cohesion: 0.4
Nodes (8): _record(), test_all_scales(), test_all_zones(), test_database(), test_scale(), test_sht30(), test_thermocouples(), test_zone()

### Community 11 - "Fan GPIO Control"
Cohesion: 0.25
Nodes (8): cleanup(), init_fans(), fan_gpio.py — GPIO fan control abstraction for SmartSake.  GPIO pin numbers ar, Set up GPIO output pins for all configured fan zones., Drive the GPIO pin for a zone HIGH (on) or LOW (off).      Args:         zone, Release GPIO resources on shutdown., set_fan(), _try_import()

### Community 12 - "DB Backup Operations"
Cohesion: 0.5
Nodes (2): Auto-prune oldest unlocked runs when disk space is low., run_prune()

### Community 13 - "SHT30 Calibration"
Cohesion: 0.83
Nodes (3): main(), _read_direct(), _read_from_file()

### Community 14 - "Fan Control Evaluation"
Cohesion: 1.0
Nodes (1): PID Fan Control

### Community 15 - "Smoke Test"
Cohesion: 1.0
Nodes (2): Hardware Smoke Test, test_hardware.py â€” Hardware Test Script

### Community 16 - "SmartSake System"
Cohesion: 1.0
Nodes (1): SmartSake Graph Report

### Community 17 - "Sensor JSON Output"
Cohesion: 1.0
Nodes (1): sensor_latest.json

### Community 18 - "Run History Page"
Cohesion: 1.0
Nodes (1): history.html â€” Run Detail Table

### Community 19 - "Run Summary Page"
Cohesion: 1.0
Nodes (1): summary.html â€” Hourly Stats

## Knowledge Gaps
- **122 isolated node(s):** `Insert built-in koji reference curves if none exist yet.`, `data keys: tc1-tc6, sht_temp, humidity, fan1-fan6, weight_lbs, weight_lbs_1..4 (`, `Return up to n evenly-strided readings for run_id.`, `rows: list of dicts with elapsed_min, temp_target`, `Return the active override for a zone, or None if absent/expired.` (+117 more)
  These have ≤1 connection - possible missing edges or undocumented components.
- **Thin community `Fan Control Evaluation`** (2 nodes): `evaluate_fan_state()`, `PID Fan Control`
  Too small to be a meaningful cluster - may be noise or needs more connections extracted.
- **Thin community `Smoke Test`** (2 nodes): `Hardware Smoke Test`, `test_hardware.py â€” Hardware Test Script`
  Too small to be a meaningful cluster - may be noise or needs more connections extracted.
- **Thin community `SmartSake System`** (1 nodes): `SmartSake Graph Report`
  Too small to be a meaningful cluster - may be noise or needs more connections extracted.
- **Thin community `Sensor JSON Output`** (1 nodes): `sensor_latest.json`
  Too small to be a meaningful cluster - may be noise or needs more connections extracted.
- **Thin community `Run History Page`** (1 nodes): `history.html â€” Run Detail Table`
  Too small to be a meaningful cluster - may be noise or needs more connections extracted.
- **Thin community `Run Summary Page`** (1 nodes): `summary.html â€” Hourly Stats`
  Too small to be a meaningful cluster - may be noise or needs more connections extracted.

## Suggested Questions
_Questions this graph is uniquely positioned to answer:_

- **Are the 20 inferred relationships involving `HX711` (e.g. with `Return {zone: [(elapsed_min, temp_target)]} — one shared curve for all zones.` and `Linearly interpolate target temp at elapsed_min. Clamps at edges.`) actually correct?**
  _`HX711` has 20 INFERRED edges - model-reasoned connections that need verification._
- **Are the 5 inferred relationships involving `server.py â€” Flask API Server` (e.g. with `flask>=3.0 Dependency` and `db.py â€” SQLite Database Layer`) actually correct?**
  _`server.py â€” Flask API Server` has 5 INFERRED edges - model-reasoned connections that need verification._
- **What connects `Insert built-in koji reference curves if none exist yet.`, `data keys: tc1-tc6, sht_temp, humidity, fan1-fan6, weight_lbs, weight_lbs_1..4 (`, `Return up to n evenly-strided readings for run_id.` to the rest of the system?**
  _122 weakly-connected nodes found - possible documentation gaps or missing edges._
- **Should `Database Layer` be split into smaller, more focused modules?**
  _Cohesion score 0.03 - nodes in this community are weakly interconnected._
- **Should `Flask API Routes` be split into smaller, more focused modules?**
  _Cohesion score 0.03 - nodes in this community are weakly interconnected._
- **Should `HX711 Scale Driver` be split into smaller, more focused modules?**
  _Cohesion score 0.05 - nodes in this community are weakly interconnected._
- **Should `Server Endpoints` be split into smaller, more focused modules?**
  _Cohesion score 0.03 - nodes in this community are weakly interconnected._

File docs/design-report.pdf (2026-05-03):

# DESIGN REPORT: SMART SAKE TABLE

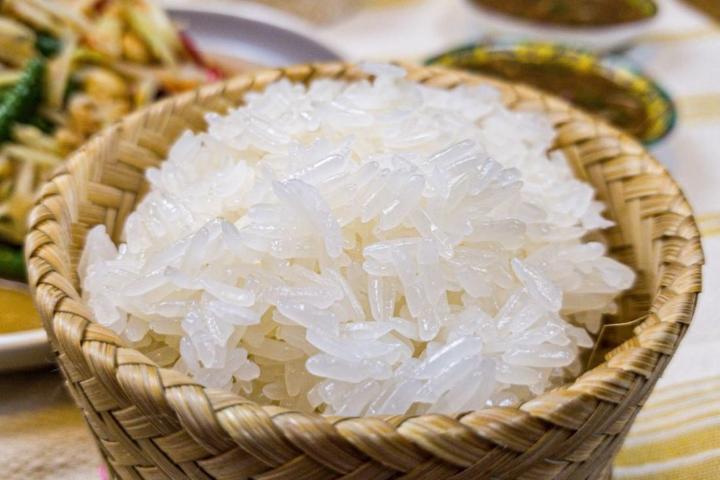
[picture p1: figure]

SMART SAKE TABLE

NATALIE CUPPLES, MAKENNA HULL, BENJAMIN LIN, ANASTASIA MYERS

BAE 402 DESIGN IN BIOSYSTEMS ENGINEERING I

NOVEMBER 10TH

, 2025

Smart Sake Table | Design Report

## Executive Summary

Sake is a traditional Japanese alcoholic beverage; one step of sake’s fermentation process involves the controlled growth of koji mold over rice. The current koji growth process at Void Sake Co. is time-consuming and labor intensive. The process relies on in-person qualitative analysis of the koji. If koji growth is left unchecked, it may overgrow or undergo a process called sporulation. Sporulation can be expedited by high temperatures or high humidity; it is also known to introduce unwanted flavors to the final sake product. Currently, each time koji is grown at The Void Sake Co. The head brewer must remain on the premises for the duration of the growth stage. This practice is unsustainable, given intense time and labor commitments.

The proposed design to monitor koji growth at The Void Sake Co. is a smart sake table. The smart sake table will reduce the amount of labor required during the koji growth stage. The design consists of six fans, paired with six temperature probes. The system aims to regulate the temperature of the koji bed without physical mixing. The design structure is based on the current koji table at Void Sake Co.

A dashboard mounted near the table allows the user to observe live readings for temperature, fan power, humidity, and table weight throughout the duration of the run. The user can use this live data to monitor and adjust the koji growth parameters, including physically mixing the rice bed if necessary. The design will reduce the amount of work required to grow the koji mold.

## Table of Contents

## Introduction

### Purpose

The process of fermentation is required in the production of alcoholic beverages. The sake, or Japanese rice wine, brewing is a unique process that is very labor intensive and artisanal, relying on both solid and liquid fermentation steps. In the solid fermentation step, a bed of rice is fermented using a traditional koji table. This table allows brewers to monitor and manipulate fungus growth. Currently, this process is labor-intensive, time-consuming, and difficult to standardize, as it depends on the subjective and qualitative analysis done by the brewer.

As the growth cycle of koji mold is in the brewer’s control, deviations from allowed temperature and humidity ranges can lead to an undesired final product. A common problem with koji is the risk of sporulation, or overgrowth of the mold (Inoue, 2016). Sporulation is often signaled by a color change in the rice, which is why koji growth and its environmental conditions must constantly be monitored by the brewer. This color change signaling sporulation can be difficult to notice, often occurring within the bed of rice. The issue of sporulation can lead to waste and large expenses. As much of the current monitoring relies on visual cues, a solution that allows for consistent products is required to save both money and time.

### Research

Koji is a filamentous fungus, or a type of mold. However, the term koji also refers to rice that has already been inoculated with mold spores (Uwajimaya, 2025). The process for producing koji, which is used to create sake, originated in Japan and has become increasingly popular in the United States. In Japan, “sake” is a generic term to describe alcoholic beverages. When describing sake, the Japanese use the term "nihonshu" (Roussille, 2018). As seen in Figure A-1, the production of sake involves multiple steps. This includes rice steaming, koji making, fermentation, and pressing. For this project, the focus is on the koji making process. The most popular way to produce koji is by spore-inoculating a koji mold, Aspergillus oryzae, on a bed of steamed rice as outlined in Figure A-2. Koji produced this way is then suitable to produce fermented food products (Japan Patent No. 4115591, 1977).

Many important factors must be considered when designing a koji room. Insulation to prevent condensation, maintaining a set temperature and humidity, and ventilating to remove heat, water, and carbon dioxide from koji growth are critical design factors (Wong, 2021). The temperature-time curve gives insight into the different setpoints for the koji process as shown in Figure B-1. Due to spore growth and germination having different optimal temperatures, we cannot set a single temperature for the entire fermentation process (Wong, 2021). When looking at specific temperature growth curves, we see that there are no phases of high and low temperatures. Instead, there are specific points of growth where the koji bed requires high temperature, such as around five hours, and a need for low temperatures at approximately twenty-two hours (Inoue, 2016). Understanding these different constraints and desired ranges is important when working to improve the existing system.

### Relevant Standards

When working with koji to produce sake, there are a number of standards to adhere to ensure safety, reliability, and competency. Standard ANSI/ASAE D241.4 provides information surrounding the specific gravity, air space, and moisture content in rice kernels on a bulk basis. During the fermentation of koji, steamed rice absorbs water to allow for koji growth. Knowing these mass-moisture relationships for rice is important to ensure proper koji fermentation and to avoid sporulation. This standard will help the group to determine how the moisture content in the rice changes over time. Similarly, standard ASAE D243.5 provides data and equations to aid in estimating thermal properties for cereal grains, including rice. This standard has temperature ranges and thermal conductivity values for multiple styles of rice. These values will help with creating setpoints for the temperature gauges that we plan to program during our testing and build phase, and for use in the operation of our project. Standard ANSI/ASAE S448.2 provides even more insight into the properties of rice. Since rice is the vessel in which koji is produced, the team found it important to gather multiple standards around its attributes. This standard is especially applicable as it is geared toward thin layers of grain. This standard lays out an experiment to measure the moisture content in rice and provides constants to use in these equations as well. As previously mentioned, the team is interested in the moisture content in the rice during fermentation in the koji room. This standard provides instruction on how the moisture content can be calculated.

The koji room has high humidity. When designing a new system for this space, one must consider the materials that can withstand these high levels of temperature and humidity. The EPA provides guidelines to follow to ensure that moisture is controlled. In EPA 402-F-13053, the EPA clarifies that moisture control does not require everything to be kept completely dry; vulnerable materials just need to be kept “dry enough”. Standard ASAE D243.5 discusses the wide range of digital thermometers that can be used in engineering applications. As the team continues to design our system, this information is valuable in deciding which thermometer to use when working in a koji room, keeping in mind the conditions of the room that the thermometer must be tolerant of. If the new additions to the table cannot withstand the environment of the koji room, the koji could become contaminated. Then, sake later produced would not be viable for sale and consumption. Ensuring that we have the proper equipment and materials to meet industry standards will be a crucial part of the planning process for this smart sake table project.

Another important aspect to consider is that food safety standards will have to be followed. There are specific requirements for materials and devices used in the production of consumable products, as highlighted by the FDA. Following their approved list of safe materials for encountering food during the inoculation and brewing process will be pertinent to ensuring the design of the system complies with federal standards (U.S. Food and Drug Administration, 2023).

## Problem Statement

Sake production is an artisanal Japanese practice growing in the USA. Traditional production relies on subjective in-person analysis, such as monitoring temperature, humidity, and color to prevent sporulation. Sporulation, the overgrowth of koji, leads to loss of product, more specifically 140kg of rice, 20 hours of labor, and additional lead times. A system to standardize control of koji growth without compromising the appearance of the current table would benefit the Void Sake Company.

## Design Constraints

This project requires consideration of various constraints to ensure that the design meets safety and reliability standards. One constraint in this design is space- the design solution must feet inside the 12’ x 10’ x 7’ foot room. The size of the table koji rice is made on must also be kept in mind, as it is 6’ by 4’ and has a table tray depth of 5”. Another facility constraint is the available power sources, as all plugs within and outside of the room operate on the same 110V, 60Hz, 20A breaker. There is also no Wi-Fi on site, so the design cannot utilize off-site remote control via an app. Looking at design constraints, the materials used in this project must work in a humid environment. More specifically, they will need to be moisture and rot resistant and food-grade. Finally, the traditional aspect of koji making must be respected, with the rice being mixed by hand.

## Design Considerations and Criteria

When designing the smart sake table, the cost, design, and process must be taken into consideration. The team has not been given a set budget but knows that the funding will be minimal. The design will also need to be easy to operate, as the facility does not have an engineer on-site. As previously mentioned, the traditional process must be respected, so the koji table will need minimal modification. This process requires manual labor and movement around the koji room, so reduced trip hazards must be considered to prevent the chances of bumps, trips, and falls.

The criteria selected for this smart sake table design is as follows:
- Record temperature of koji rice
- Record weight of rice
- Record humidity
- Automate fans
- Data visualization
- Easy operation
- Minimal human intervention

## Proposed Solution

The proposed design is a controlled drying table that helps koji rice dry evenly by managing airflow, humidity, and temperature inside the space. The table includes a raised perforated tray to hold the rice, six box fans that push air across the surface, and a dehumidifier to keep the moisture level within the proper range. Sensors such as thermocouples and load cells are built into the structure so the system can monitor temperature, dryness, and weight changes during the drying process. As shown in Figure 1, the exploded view highlights how the frame, multiple fan housings, load cells, and table components fit together to create a stable and easy-to-assemble system. This layout supports good airflow distribution, accessible wiring paths, and clear sensor placement, helping ensure the table performs consistently and can be controlled through the PLC. All of the sensor data will be sent to the PLC and then displayed on a connected monitor, where users can view temperature, humidity, and rice weight in real time. The system will also send the same information to an easy-to-use browser app, allowing users to check the status of the drying process from anywhere.

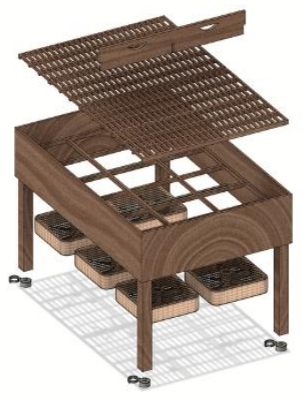
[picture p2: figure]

Figure 1: Exploded view of Koji Table

## Budget and Bill of Materials

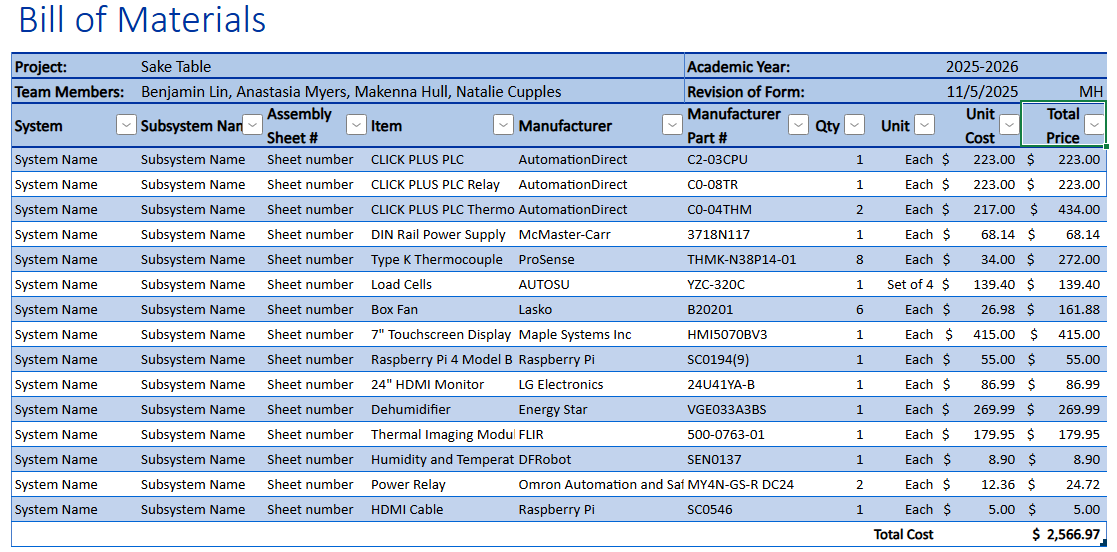
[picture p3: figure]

## Conclusion and Recommendation(s)

### Conclusion

The current koji growth method at Void Sake Co. Is time-consuming, labor intensive. To prevent sporulation of the koji, this process relies heavily on in-person qualitative analysis of the koji growth and hand mixing to reduce rice bed temperature. However, the introduction of a smart sake table will reduce the amount of labor associated with each koji batch. The smart sake table will monitor and automatically remediate extreme rice temperatures, allowing the user to spend more time away from the run.

The system utilizes temperature probes to track temperature, paired with fans mounted underneath the bed to lower the bed temperature if needed. The included dashboard communicates live stats including temperature, humidity and power levels of the fans. The design is meant to conform to the current Void Sake Co. koji table, as well as omitting an automatic mixing component.

### Recommendation(s)

The current koji growth method at Void Sake Co. is heavily dependent on subjective, in-person analysis and is extremely labor-intensive. This reliance risks sporulation which results in lost product, labor hours, and extended lead times.

The proposed Smart Sake Table design is the necessary solution to standardize and automate the growth environment. The system, utilizing fans, a dehumidifier, and temperature probes, actively monitors and regulates the rice bed temperature without requiring physical mixing. Live data on temperature, humidity, and fan power is displayed on a nearby dashboard, replacing the need for constant, qualitative, human observation.

Based on the evidence that the Smart Sake Table effectively reduces the primary risks and labor constraints of the current process, immediate approval for the manufacturing and installation of the system is strongly recommended. This step will ensure product consistency, prevent costly batch losses, and significantly reduce the brewer's required time commitment.

## References

ANSI/ASAE. (2014). Thin-Layer Drying of Agricultural Crops. (S448.2). https://asabe.org/

ANSI/ASAE. (1992). Density, Specific Gravity, and Mass-Moisture Relationships of Grain for Storage.

(D241.4). https://asabe.org/

ASAE. (2024). Thermal Properties of Grain and Grain Products. (D243.5). https://asabe.org/

ASTM. (2019). Standard Guide for Digital Contact Thermometers. (E2877-12). https://www.astm.org/

Fumio Noda, K., Mogi, K., & Toshio Sakassai. (1977). Japan Patent No. 4115591.

Inoue, D. T. (2016). Textbook of Sake Brewing. Brewing Society of Japan.

Roussille, G. (2018). Nihonshu: Japanese Sake. Gautier Roussille.

Uwajimaya. (2025). Retrieved 2025, from Uwajipedia: https://www.uwajimaya.com/uwajipedia/koji/

Wong, K. (2021, September 7). Design of the koji room (koji-muro) . Retrieved from Controlled Mold:

https://controlledmold.com/design-of-the-koji-room-koji-muro/

Wong, K. (2021, July 28). The koji making process. Retrieved from Sake Brewers Guild:

https://www.brewsake.org/advanced/the-koji-making-process-temperature-mycelium-moisture

## Appendix A: Sake Brewing and Koji Processing

The sake brewing process is a multi-stage process, often starting from polished rice to product distribution. In this process, the key point of interest is the koji making step. Koji starts with the addition of freshly steamed rice and ends with arresting the growth of koji on rice and moving the medium to a fermentation vessel. Figure A-1 shows the overall key steps in sake production.

Figure A-1. Overview Process Flow Chart for Sake Brewing

Figure A-2 shows a more detailed view of the koji inoculation process. The steamed rice intended for koji inoculation is spread evenly onto the table to cool. Once cold enough, spores are shaken onto the bed of rice and mixed in by hand. Following spore inoculation, the rice is then packed into a pile and covered to promote initial koji mycelium growth, allowing for the koji to establish itself in the grains for the rest of the process. Finally, it is spread out and mixed following specific temperatures and humidity to produce enzymes.

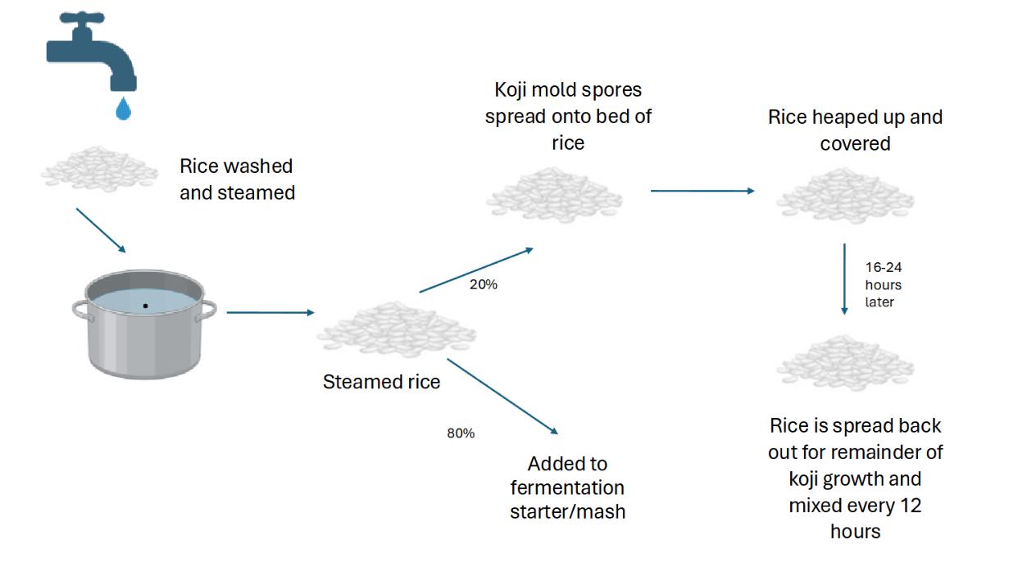
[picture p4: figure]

Figure A-2 Koji Inoculation

## Appendix B: Koji Temperature Graph

Koji inoculation follows intentional changes in temperature over time. The purpose of changing the environment is to support production of specific enzymes, such as amylases and proteases. Producing these enzymes is an essential component of koji, as it is used in fermentation for breaking down rice grains into simple sugars. The high temperature hold is also used to arrest the koji growth, keeping it from using energy to produce spores, which lowers the sugar concentration and introduces off tastes into the product.

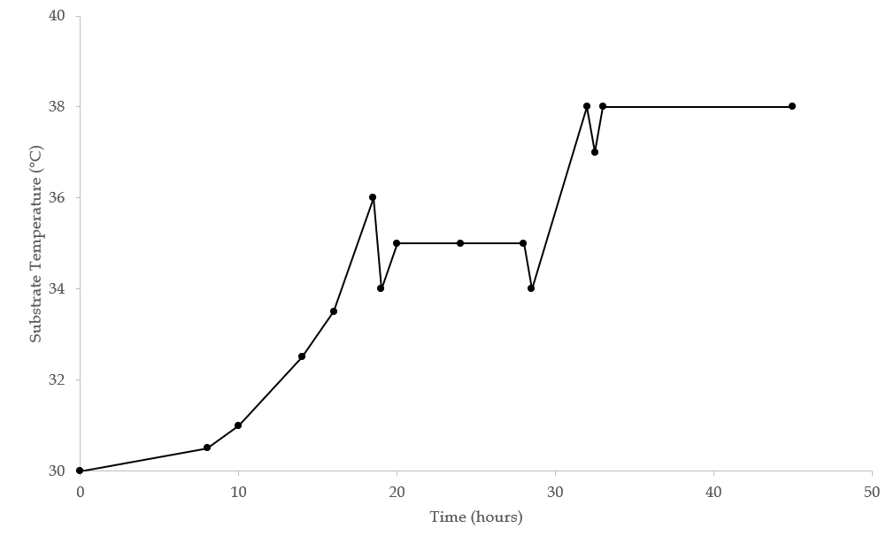
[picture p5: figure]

Figure B-1. Koji Temperature Graph for Inoculation

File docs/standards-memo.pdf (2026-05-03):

# Sake Table Standards Memo

TO: Dr. Alicia Modenbach and Dr. Michael Peterson, BAE 402 Instructors FROM: Benjamin Lin, BAE Student
DATE: October 17th, 2025
SUBJECT: Summary of Four Standards for Sake Table Design

The purpose of this memo is to identify four industry standards applicable to the smart sake table project. The standards will guide design decisions for material selection, electronics selection, system reliability, and product bioprocessing. They ensure that the system will withstand environmental stresses while maintaining food safety and functionality.

RELEVANT STANDARDS

Thin Layer Drying of Agricultural Crops - American Society of Agricultural and Biological Engineers, 2022
Provides procedures for modeling drying characteristics of grains and other biomaterials. System calibration, component selection, and validation of the smart sake table’s humidity and temperature control systems will reference this standard during design and testing phases. This will support consistent growth, drying, and temperature conditions throughout the process.

Food Equipment Materials - NSF International, 2018
Defines sanitary and toxicity guidelines for choosing materials with direct food contact in processing equipment. This standard specifically shows selection for choice of polymer, metal, wood, tubing, and gasket which are expected for the electrical and physical applications of the project. This will be referenced during the design and building phase of the project.
Environment Testing: General and Guide - International Electrotechnical Commission, 2013
Provides general framework for choosing electrical components for extensive environmental conditions like humidity, temperature, and vibrations. This standard applies to the electrical components of the project, ensuring design validation and reliability in the humid, hot environments. This will be referenced during the testing and building phases of the project.
Density, Specific Gravity, and Mass-Moisture Relationships of Grain Storage - American Society of Agricultural Engineers, 1992
Describes density, specific gravity, and moisture content for different stored grains. This standard will inform the drying and temperature control process in rice processing. It will apply to the design and testing phases of the project, as well as additional modeling information for a COMSOL proof of concept. Integrating these standards will support safe, reliable, and consistent operation of the smart sake table. They provide a foundation for following food-grade standards, ensuring mechanical and electrical performance, and informed component selection. Thank you for reviewing this memo.

REFERENCES
American Society of Agricultural and Biological Engineers. (2022). ANSI/ASAE S448.2 SEP2014 (R2022):

Thin-Layer Drying of Agricultural Crops. https://elibrary.asabe.org/abstract.asp?aid=49062

American Society of Agricultural Engineers. (1992). ANSI/ASAE D241.4 OCT1992: Density, Specific

Gravity, and Mass–Moisture Relationships of Grain for Storage. https://elibrary.asabe.org/

International Electrotechnical Commission. (2013). IEC 60068-1: Environmental Testing – Part 1: General

and Guidance.

https://cdn.standards.iteh.ai/samples/12875/079778b390164368a49437b30d03ffd9/IEC-

60068-1-2013.pdf

NSF International. (2018). NSF/ANSI 51: Food Equipment Materials. https://www.nsf.org/nsf-

standards/standards-portfolio/food-equipment-standards

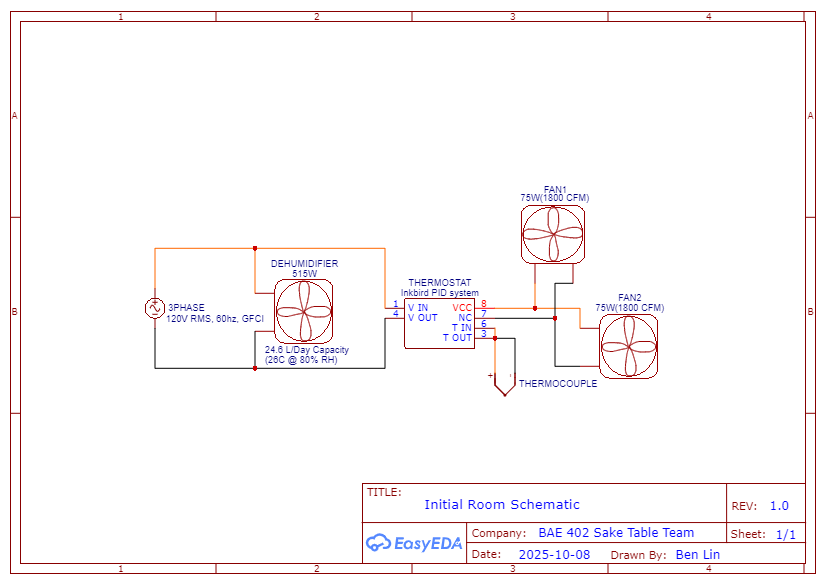
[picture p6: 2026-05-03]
docs/schematics/koji-room-layout.png

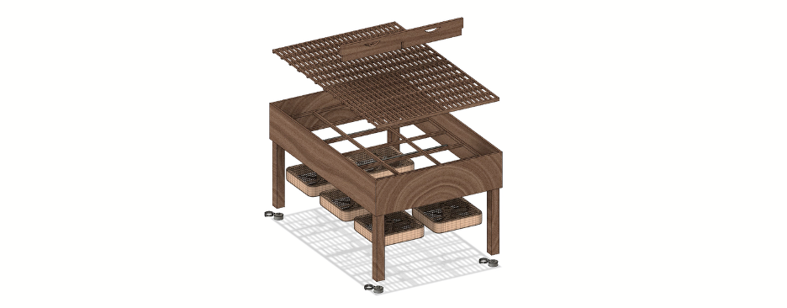
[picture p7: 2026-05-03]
hardware/cad/sake-table-exploded.png

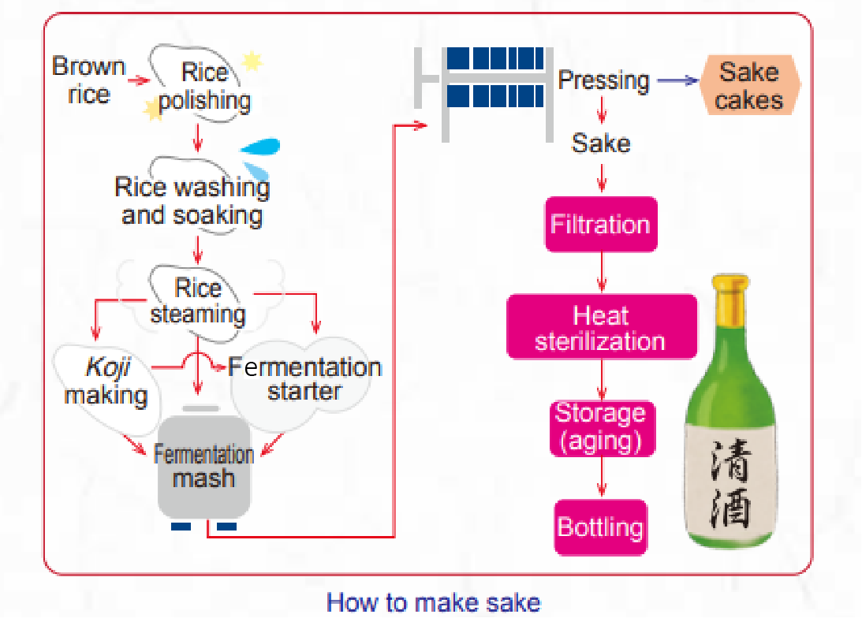
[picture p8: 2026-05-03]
docs/brewing-flow-chart.png

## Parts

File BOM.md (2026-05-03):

# Bill of Materials — Sake Table (RPi Version)

**Project:** Sake Table
**Team:** Benjamin Lin, Anastasia Myers, Makenna Hull, Natalie Cupples
**Academic Year:** 2025-2026
**Last Revised:** 2026-02-09 (NC)

---

## Components

| Item | Manufacturer | Mfr Part # | Qty | Unit | Unit Cost | Total | Supplier | Supplier Part # |
|---|---|---|---|---|---|---|---|---|
| Load Cells (100 lb max) | TE Connectivity | FX293X-100A-0100-L | 4 | Each | $24.49 | $97.96 | DigiKey | 223-FX29K0-100A-0100-L-ND |
| Box Fan | Lasko | B20201 | 6 | Each | $26.98 | $161.88 | Home Depot | 399582 |
| Type K Thermocouples | Adafruit | 3245 | 6 | Each | $9.95 | $59.70 | DigiKey | 1188-SNS-TMP-DS18B20-MAXIM-ND |
| Raspberry Pi 4 Model B | Raspberry Pi | SC0194(9) | 1 | Each | $75.00 | $75.00 | DigiKey | 2648-SC0194(9)-ND |
| 24" HDMI Monitor | LG Electronics | 24U41YA-B | 1 | Each | $86.99 | $86.99 | Best Buy | 24U41YA-B |
| Dehumidifier | Energy Star | VGE033A3BS | 1 | Each | $269.99 | $269.99 | Vellgoo | VGE033A3BS |
| Load Cell Amplifier (HX711) | Avia Semiconductor | HX711 | 4 | Each | $11.50 | $46.00 | SparkFun | SEN-13879 |
| Humidity/Temp Sensor (SHT30) | DFRobot | SEN0137 | 1 | Each | $24.95 | $24.95 | DigiKey | 1528-4099-ND |
| HDMI Cable (micro-to-full) | Raspberry Pi | SC0546 | 1 | Each | $5.00 | $5.00 | DigiKey | 2648-SC0546-ND |
| 8-Channel Relay Module | SunFounder | TS0012 | 1 | Each | $11.87 | $11.87 | DigiKey | 4411-TS0012-ND |
| Raspberry Pi Power Supply | Raspberry Pi | SC1412 | 1 | Each | $8.00 | $8.00 | DigiKey | 2648-SC1412-ND |
| GPIO Breakout Board | Raspberry Pi | 2711 | 1 | Each | $19.95 | $19.95 | Adafruit | — |
| Thermocouple Amplifier (MAX31850K) | Adafruit | 1727 | 6 | Each | $14.95 | $89.70 | Adafruit | MAX31850K |

---

## Cost Summary

| Scenario | Total |
|---|---|
| Full build (all components) | **$956.99** |
| Reduced build (no monitor, 4 fans) | **$546.05** |

---

## Notes

- Load cells are rated to 100 lb each (4 total for platform weighing)
- Thermocouples are Type K, read via MAX31850K amplifiers on a shared 1-Wire bus (GPIO 4)
- Relay module is active-LOW (GPIO LOW = relay energized = fan ON)
- SHT30/SHT31 humidity sensor connects via I2C (GPIO 2/3)
- HX711 amplifiers connect via GPIO 5 (DAT) and GPIO 6 (CLK) for scale 1; scales 2-4 configurable
- Box fans are 20" Lasko units, one per fermentation zone, switched via relay channels

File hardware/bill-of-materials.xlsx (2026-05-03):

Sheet: BOM Spring 26 RPi Version
Bill of Materials
Project: | Sake Table |  |  |  | Academic Year: |  | 2025-2026 |  |  |  |  | Last Revised
Team Members: | Benjamin Lin, Anastasia Myers, Makenna Hull, Natalie Cupples |  |  |  | Revision of Form: |  | 2026-02-06 |  | Initials | NC |  | 2026-02-09
Item | Manufacturer | Manufacturer Part # | Qty | Unit | Unit Cost | Total Price | Supplier | Column5 | Supplier Part # | Link to Order | Column1 | Column3 | Column32
Load Cells | TE Connectivity | FX293X-100A-0100-L | 4 | Each | $24.49 | $97.96 | DigiKey |  | 223-FX29K0-100A-0100-L-ND | Load Cells (max 100 lb) (https://www.newark.com/te-connectivity/fx293x-100a-0100-l/load-cell-100lbf-5-25v-0-to-50deg/dp/40AH0491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)
Box Fan | Lasko | B20201 | 6 | Each | $26.98 | $161.88 | Home Depot |  | 399582 | Box Fan (https://www.homedepot.com/p/Lasko-20-in-3-Speed-Air-Circulating-Box-Fan-for-Home-in-White-with-Save-Smart-Technology-1820-CFM-and-Carry-Handle-B20201/203072133)
Type K Thermocouples | Adafruit | 3245 | 6 | Each | $9.95 | $59.70 | DigiKey |  | 1188-SNS-TMP-DS18B20-MAXIM-ND | Type K Thermocouples (https://www.digikey.com/en/products/detail/adafruit-industries-llc/3245/7320194?gclsrc=aw.ds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)
Raspberry Pi 4 Model B | Raspberry Pi | SC0194(9) | 1 | Each | $75.00 | $75.00 | DigiKey |  | 2648-SC0194(9)-ND | Raspberry Pi Model 4B (https://www.digikey.com/en/products/detail/raspberry-pi/SC0194-9/10258781)
24" HDMI Monitor | LG Electronics | 24U41YA-B | 1 | Each | $86.99 | $86.99 | Best Buy |  | 24U41YA-B | Monitor (https://www.bestbuy.com/product/lg-24-ips-fhd-120hz-monitor-with-hdr10-hdmi-black/JJ8VPZKPZZ)
Dehumidifier | Energy Star | VGE033A3BS | 1 | Each | $269.99 | $269.99 | Vellgoo |  | VGE033A3BS | Dehumidifier (https://vellgoo.com/products/4-500-sq-ft-energy-star-dehumidifier-for-basement-with-drain-hose-52-pint-drytank-series-dehumidifiers-for-home-large-room-intell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)
Load Cell Amplifier | Avia Semiconductor | HX711 | 4 | Each | $11.50 | $46.00 | SparkFun Electronics |  | SEN-13879 | Amplifiers (https://www.sparkfun.com/sparkfun-load-cell-amplifier-hx711.html)
Humidity and Temperature Sensor | DFRobot | SEN0137 | 1 | Each | $24.95 | $24.95 | DigiKey |  | 1528-4099-ND | Humidity Sensor (https://www.digikey.com/en/products/detail/adafruit-industries-llc/4099/10230011?gclsrc=aw.ds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)
HDMI Cable | Raspberry Pi | SC0546 | 1 | Each | $5.00 | $5.00 | DigiKey |  | 2648-SC0546-ND | HDMI Cable (https://www.digikey.com/en/products/detail/raspberry-pi/SC0546/13901220?gclsrc=aw.ds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)
8 Channel Relay Module | SunFounder | TS0012 | 1 | Each | $11.87 | $11.87 | DigiKey |  | 4411-TS0012-ND | Relay Module (https://www.digikey.com/en/products/detail/sunfounder/TS0012/18668607?s=N4IgTCBcDaICoGUAMSCMEC6BfIA)
Raspberry Pi Power Supply | Raspberry Pi | SC1412 | 1 | Each | $8.00 | $8.00 | DigiKey |  | 2648-SC1412-ND | Power Supply (https://www.digikey.com/en/products/detail/raspberry-pi/SC1412/10258762?gclsrc=aw.ds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)
Breakout Board | Raspberry Pi | 2711 | 1 | Each | $19.95 | $19.95 | Adafruit |  |  | Breakout Board (https://www.digikey.com/en/products/detail/sunfounder/TS0012/18668607?s=N4IgTCBcDaICoGUAMSCMEC6BfIA)
Thermocouple Amplifier | Adafruit | 1727 | 6 | Each | $14.95 | $89.70 | Adafruit |  | MAX31850K | Thermocouple Amplifiers (https://www.homedepot.com/p/Lasko-20-in-3-Speed-Air-Circulating-Box-Fan-for-Home-in-White-with-Save-Smart-Technology-1820-CFM-and-Carry-Handle-B20201/203072133)
 |  |  |  |  | Total | $956.99
 |  |  |  |  | Total | $546.05
 |  |  |  |  | what we'll spend if we get a monitor and only buy four fans

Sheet: BOM for poster
Item | Manufacturer | Manufacturer Part # | Qty | Unit | Unit Cost | Total Price | Supplier | Column5 | Supplier Part # | Link to Order | Column1 | Column3 | Column32
Load Cells | TE Connectivity | FX293X-100A-0100-L | 4 | Each | $24.49 | $97.96 | DigiKey |  | 223-FX29K0-100A-0100-L-ND | Load Cells (max 100 lb) (https://www.newark.com/te-connectivity/fx293x-100a-0100-l/load-cell-100lbf-5-25v-0-to-50deg/dp/40AH0491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)
Box Fan | Lasko | B20201 | 6 | Each | $26.98 | $161.88 | Home Depot |  | 399582 | Box Fan (https://www.homedepot.com/p/Lasko-20-in-3-Speed-Air-Circulating-Box-Fan-for-Home-in-White-with-Save-Smart-Technology-1820-CFM-and-Carry-Handle-B20201/203072133)
Type K Thermocouples | Adafruit | 3245 | 6 | Each | $9.95 | $59.70 | DigiKey |  | 1188-SNS-TMP-DS18B20-MAXIM-ND | Type K Thermocouples (https://www.digikey.com/en/products/detail/adafruit-industries-llc/3245/7320194?gclsrc=aw.ds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)
Raspberry Pi 4 Model B | Raspberry Pi | SC0194(9) | 1 | Each | $75.00 | $75.00 | DigiKey |  | 2648-SC0194(9)-ND | Raspberry Pi Model 4B (https://www.digikey.com/en/products/detail/raspberry-pi/SC0194-9/10258781)
24" HDMI Monitor | LG Electronics | 24U41YA-B | 1 | Each | $86.99 | $86.99 | Best Buy |  | 24U41YA-B | Monitor (https://www.bestbuy.com/product/lg-24-ips-fhd-120hz-monitor-with-hdr10-hdmi-black/JJ8VPZKPZZ)
Dehumidifier | Energy Star | VGE033A3BS | 1 | Each | $269.99 | $269.99 | Vellgoo |  | VGE033A3BS | Dehumidifier (https://vellgoo.com/products/4-500-sq-ft-energy-star-dehumidifier-for-basement-with-drain-hose-52-pint-drytank-series-dehumidifiers-for-home-large-room-intell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)
Load Cell Amplifier | Avia Semiconductor | HX711 | 4 | Each | $11.50 | $46.00 | SparkFun Electronics |  | SEN-13879 | Amplifiers (https://www.sparkfun.com/sparkfun-load-cell-amplifier-hx711.html)
Humidity and Temperature Sensor | DFRobot | SEN0137 | 1 | Each | $24.95 | $24.95 | DigiKey |  | 1528-4099-ND | Humidity Sensor (https://www.digikey.com/en/products/detail/adafruit-industries-llc/4099/10230011?gclsrc=aw.ds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)
HDMI Cable | Raspberry Pi | SC0546 | 1 | Each | $5.00 | $5.00 | DigiKey |  | 2648-SC0546-ND | HDMI Cable (https://www.digikey.com/en/products/detail/raspberry-pi/SC0546/13901220?gclsrc=aw.ds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)
8 Channel Relay Module | SunFounder | TS0012 | 1 | Each | $11.87 | $11.87 | DigiKey |  | 4411-TS0012-ND | Relay Module (https://www.digikey.com/en/products/detail/sunfounder/TS0012/18668607?s=N4IgTCBcDaICoGUAMSCMEC6BfIA)
Raspberry Pi Power Supply | Raspberry Pi | SC1412 | 1 | Each | $8.00 | $8.00 | DigiKey |  | 2648-SC1412-ND | Power Supply (https://www.digikey.com/en/products/detail/raspberry-pi/SC1412/10258762?gclsrc=aw.ds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)
Breakout Board | Raspberry Pi | 2711 | 1 | Each | $19.95 | $19.95 | Adafruit |  |  | Breakout Board (https://www.digikey.com/en/products/detail/sunfounder/TS0012/18668607?s=N4IgTCBcDaICoGUAMSCMEC6BfIA)
Thermocouple Amplifier | Adafruit | 1727 | 6 | Each | $14.95 | $89.70 | Adafruit |  | MAX31850K | Thermocouple Amplifiers (https://www.homedepot.com/p/Lasko-20-in-3-Speed-Air-Circulating-Box-Fan-for-Home-in-White-with-Save-Smart-Technology-1820-CFM-and-Carry-Handle-B20201/203072133)
 |  |  |  |  | Total | $956.99
 |  |  |  |  | Total | $546.05
 |  |  |  |  | what we'll spend if we get a monitor and only buy four fans

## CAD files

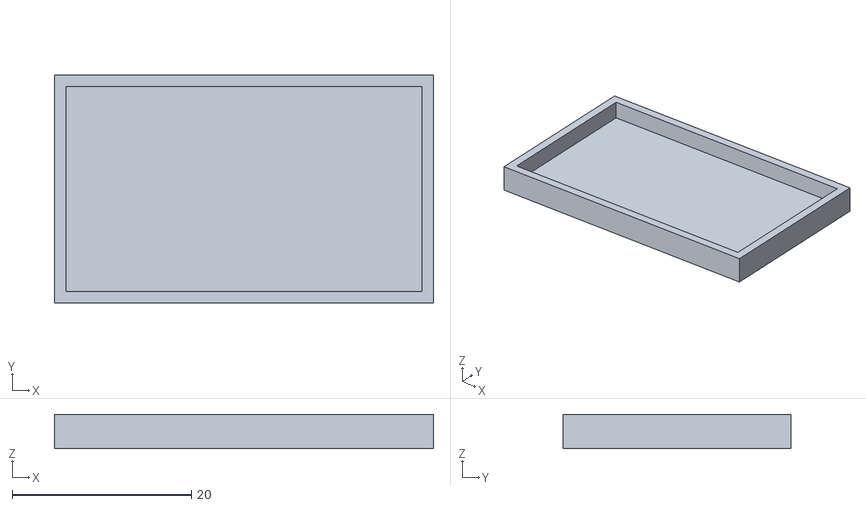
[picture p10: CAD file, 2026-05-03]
hardware/stl/load-cell-housing-lid.stl
42.3 x 25.4 x 3.81

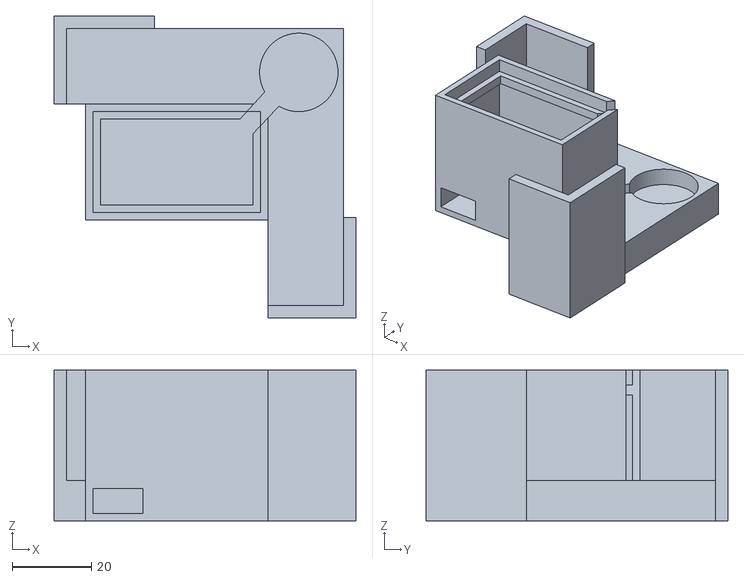
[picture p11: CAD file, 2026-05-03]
hardware/stl/load-cell-housing.stl
76.2 x 76.2 x 38.1

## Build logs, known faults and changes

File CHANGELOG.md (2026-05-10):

# Changelog

All notable changes to SmartSake. Format inspired by [Keep a Changelog](https://keepachangelog.com/en/1.1.0/);
this project does not currently version semver-style, so entries are grouped by date.

## [Unreleased] — 2026-05-09

### Added
- **`POST /api/zone-config/all`** — atomic blanket update endpoint. Body `{setpoint_c?, tolerance_c?}`
  applies the same setpoint and/or tolerance to all 6 zones in a single
  `_zone_cfg_section()`-guarded write. Replaces the previous frontend pattern of firing 6 parallel
  POSTs to `/api/zone-config`, which was racy. (`server.py`)
- **systemd watchdog ping in `WriteSensors.py`** — `sd_notify("READY=1")` at sensor-loop start
  and `sd_notify("WATCHDOG=1")` per tick (~10 s). The unit ships with `WatchdogSec=60`; this
  ping prevents the systemd watchdog from killing a healthy loop. Implementation is inline
  (writes to `$NOTIFY_SOCKET`) — no new pip dependency.
- **`CHANGELOG.md`** (this file).
- **`.gitignore`**: `sensor_data.csv` and `sensor_data.csv.*.bak` (rolling runtime artifacts).

### Changed
- **`POST /api/zone-config`** now wraps its read-merge-write in `_zone_cfg_section()` (RLock +
  atomic file replace). The lock helper already existed and was used by 4 other endpoints; the
  main zone-config POST handler was the one site not using it. Closes a real race window when
  the bulk modal fired 6 parallel requests. (`server.py`)
- **`/api/system-health`** distinguishes `{"status": "unknown"}` from `{"status": "ok"}` when
  `/run/smartsake/sensor_status.json` does not yet exist on disk. Previously the missing-file
  case fell through to `"ok"`, masking a dead sensor loop. (`server.py:388`)
- **Update Setpoints modal** simplified to blanket-only. Single setpoint + tolerance pair →
  one `POST /api/zone-config/all`. The previous six-row per-zone editor was redundant with the
  per-zone modal that opens from each zone card on the dashboard. IIFE shrunk from 264 → ~110
  lines. (`dashboard.html`)
- **`scale_config.json`** rewritten with the full per-cell schema (`dat_pin`, `clk_pin`,
  `tare_offset`, `calibration_factor`) for all 4 scales. Pin map matches CLAUDE.md GPIO
  reservations (`5/6, 12/15, 16/19, 20/21`). The previous file held only `{"scales": {"2":
  {"tare_offset": 301}}}`, which raised `KeyError: 'dat_pin'` in `load_scale_config()` and
  silently disabled all 4 cells.
- **`zone_config.json`** re-merged into a single valid JSON object. The previous file had an
  unmatched closing brace mid-file with `zone4` declared after the close, which caused every
  `GET/POST /api/zone-config` request to return 500.
- **README** — documents the new `/api/zone-config/all` endpoint, the simplified blanket modal,
  the systemd watchdog ping, the watchdog drop-in escape hatch, and the `system-health
  "unknown"` semantic.

### Fixed
- HX711 amps for all four cells now initialize on boot (was failing silently due to
  `scale_config.json` schema mismatch — see above).
- `GET/POST /api/zone-config` returns 200 again (was returning 500 due to malformed
  `zone_config.json`).

### Operational notes (not in repo, but applied to the live Pi)
- Drop-in `/etc/systemd/system/smartsake.service.d/no-watchdog.conf` was installed during
  debugging to disable `WatchdogSec` while the new `sd_notify` ping was being verified. Once
  the ping is confirmed stable in the field, this drop-in can be removed (`sudo rm
  /etc/systemd/system/smartsake.service.d/no-watchdog.conf && sudo systemctl daemon-reload &&
  sudo systemctl restart smartsake`) to re-enable the watchdog.
- Tares for all 4 load cells were re-recorded against current empty-table raws and persisted
  in `scale_config.json` (`scale 1: 397, scale 2: 1023, scale 3: 5324, scale 4: 298`). The
  factors remain at the `8000` placeholder pending hardware fixes — see test artifact
  `/tmp/coupling_test.py` for the diagnostic that surfaced the load-path issue (bag weight
  not transferring to cells 1, 2, 4).

### Verification
- `test_fan_state.py` — 7 / 7 pass
- `test_failure_injection.py` — 12 / 12 pass
- `/tmp/stress_fan_live.py` (new live integration suite) — 65 / 65 pass; covers every
  decision branch (override, config setpoint, no setpoint, hysteresis), 6-way parallel
  zone-config writes (race-protection), the new blanket endpoint, validation, override
  priority over config.
- `/tmp/stress_tc_live.py` (new live integration suite) — 42 / 42 pass; covers `/api/tc-probes`
  bus health, TC liveness across ticks, calibration validation, set/clear/from-reference
  endpoints, hot-reload, and TC offset → fan eval integration (offset crosses trigger →
  fan flips state on next tick).
- **Combined: 126 / 126 pass.**

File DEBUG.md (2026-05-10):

# SmartSake Debug Playbooks

Two systems land in the field with the most ways to misbehave: **automatic relay switching** and **load cell calibration**. Each section below walks how it works, what to look at, the command cookbook, and a symptom → cause decision tree.

When in doubt, read the live state files first (`/run/smartsake/*.json`) before assuming the code is wrong. The state files are produced by the same loop that drives the relays, so they tell you exactly what the loop *thinks* is happening.

---

# Part 1 — Automatic relay switching

## How it works (one tick)

Every `SENSOR_INTERVAL_S = 10s`, `start_sensor_loop()` in `WriteSensors.py` does:

1. Hot-reload `tc_zone_map.json` (mtime check).
2. Read all 1-Wire thermocouples, median-filter each.
3. Look up the active run (`db.get_active_run()`); if there is one, call `evaluate_fan_state(run, tc_readings)`. Otherwise call `evaluate_fan_state_no_run(tc_readings)`.
4. For each zone 1–6, call `fan_gpio.set_fan(z, on)` with the desired action.
5. Write `/run/smartsake/fan_state.json` with the per-zone result + reason metadata.
6. Insert a sample row in `samples` (DB) if a run is active.

### Decision hierarchy inside `evaluate_fan_state`

For each zone 1–6, in order:

1. **DB-backed override** (`fan_overrides` table, written by dashboard "Override" UI). If present, sets `mode = "manual"`, action = `on`/`off`. Auto loop is bypassed for this zone. `_fan_on[zone]` is mirrored so a return to auto inherits the right hysteresis state.
2. **Fan rule** (`fan_rules` table — time-window or threshold rules). If a rule fires, sets `mode = "rule"`, action = the rule's `fan_action`. `_threshold_breach_start` tracks how long a threshold has been exceeded for the rule's `threshold_dur_min` requirement.
3. **Curve setpoint** (`target_temp_profile` interp from elapsed minutes). If present, sets `mode = "limit"`, source = `"curve"`.
4. **Zone-config setpoint** (`zone_config.json["zoneN"]["setpoint_c"]` or `default.setpoint_c`). Same `mode = "limit"`, source = `"config"`.
5. **No setpoint at all** → `mode = "none"`, action = `"off"`. Auto loop will never turn this fan on.

### The limit-switch math (modes 3–4)

```python
current_on = _fan_on[zone]                    # last tick's commit
trigger    = setpoint + tolerance             # default tolerance = 1.0 °C
if actual > trigger:        desired_on = True
elif actual <= setpoint:    desired_on = False
else:                       desired_on = current_on   # hysteresis band

if desired_on != current_on:
    _fan_hold_counts[zone] += 1
    if _fan_hold_counts[zone] >= DEADBAND_HOLD:   # = 1 → next tick commits
        fan_on = desired_on
        _fan_hold_counts[zone] = 0
    else:
        fan_on = current_on                       # not yet — keep last state
else:
    _fan_hold_counts[zone] = 0
    fan_on = desired_on
```

So: a zone stays in its last state inside `(setpoint, setpoint+tolerance]`. Crossing above `trigger` arms an ON transition; dropping to `setpoint` or below arms an OFF transition. With `DEADBAND_HOLD = 1` the transition commits on the next tick (~10s later), which is the relay-life protection.

### Active-LOW relays

`fan_gpio.set_fan(z, True)` writes GPIO **LOW** to the pin (relay coil energized → fan ON). False writes HIGH (coil de-energized → fan OFF). `init_fans()` sets every pin to HIGH at boot. The shutdown handler (`SIGTERM`, `SIGINT`) drives every pin HIGH then calls `cleanup()`, so a clean restart leaves all fans OFF. **`SIGKILL` and power loss bypass this** — relays hold their last state until the next boot.

### Override expiry — the subtle bug class

Both run-mode and no-run-mode overrides can have an `expires_at`. When an override expires between ticks, the zone falls back to auto. If the auto loop's hysteresis state (`_fan_on[zone]`) still says `True` from the override, and the temp is sitting inside the deadband, the fan will keep running indefinitely. Both eval functions explicitly call `reset_auto_hysteresis(z)` for any zone whose override just disappeared (`_last_run_override_zones - override_zones` in the run path; `_purge_expired_no_run_overrides` for the no-run path). If you ever see a fan stuck on after a manual override expires, check this is still firing.

### What gets logged

- `[fan]` lines — per-transition events: override start/expiry, hysteresis reset, GPIO write failures.
- `[fan-auto]` lines — every ~60s (every 6 ticks): one-line summary across all zones, e.g. `[fan-auto] z1:21.3→OFF(sp=22,tr=23) | z2:24.7→ON(sp=22,tr=23) | z3:noTC | z4:MAN-on | z5:no-sp | z6:21.0→OFF(sp=22,tr=23)`.
- All goes through stdout, captured by journalctl.

---

## Diagnostic command cookbook (auto fan)

```bash
# Live fan log (transitions + every-60s summary)
journalctl -u smartsake -f | grep -E '\[fan'

# Boot log — was init_fans() called, are the pins set?
journalctl -u smartsake -b | grep -E 'Fan zone|GPIO|sensors\]'

# Current per-zone decision the loop just made
cat /run/smartsake/fan_state.json | jq
# → {"zone1": {"action": "off", "mode": "limit", "setpoint_c": 22.0, "trigger_c": 23.0, ...}, ...}

# Current temps (what the limit-switch is comparing against)
cat /run/smartsake/sensor_latest.json | jq '.tc_1, .tc_2, .tc_3, .tc_4, .tc_5, .tc_6'

# What's the actual GPIO line state? (active-LOW: 0 = fan ON, 1 = fan OFF)
pinctrl get 17,22,23,24,25,27       # newer Pi OS
gpioinfo | grep -E 'line.*(17|22|23|24|25|27):'   # libgpiod path

# Active overrides in the DB (run mode)
sqlite3 smartsake.db "SELECT run_id, zone, action, expires_at FROM fan_overrides
                      WHERE expires_at IS NULL OR expires_at > datetime('now')
                      ORDER BY zone;"

# Active no-run overrides
cat no_run_overrides.json 2>/dev/null | jq

# Active rules for current run
sqlite3 smartsake.db "SELECT * FROM fan_rules WHERE enabled=1
                      AND run_id=(SELECT id FROM runs WHERE ended_at IS NULL LIMIT 1);"

# Current zone setpoints + tolerances (the file the auto loop reads)
cat zone_config.json | jq

# Smoke-test the fan state machine without hardware (uses mocked db + GPIO)
python3 test_fan_state.py

# Failure-injection coverage (mocks set_fan/insert_reading raising mid-tick)
python3 test_failure_injection.py

# Force every relay OFF immediately, no service interaction
python3 -c "import fan_gpio; fan_gpio.init_fans(); [fan_gpio.set_fan(z, False) for z in range(1,7)]; fan_gpio.cleanup()"
```

## Symptom → cause decision tree (auto fan)

### "Fan won't turn on"

1. **Is there a manual override locking it OFF?**
   `cat /run/smartsake/fan_state.json | jq '.zoneN.mode'` — if `"manual"`, the override is winning. Check `fan_overrides` (run) or `no_run_overrides.json`.
2. **Is there a setpoint at all?**
   Mode `"none"` means no curve and no `zone_config.json` setpoint resolved for this zone. The limit-switch never runs. Either start a run with a curve, or set `zone_config.json["zoneN"]["setpoint_c"]`.
3. **Is the TC reading present?**
   Mode `"none"` *with* a setpoint usually means `tc_map.get(zone)` returned None. Check `sensor_latest.json` for `tc_N`. If null, check `tc_zone_map.json` mapping and the 1-Wire bus (`ls /sys/bus/w1/devices/`).
4. **Is the trigger threshold being hit?**
   `[fan-auto]` log will show `z3:21.5→OFF(sp=22,tr=23)` — actual is below trigger, so OFF is correct. Either lower the setpoint/tolerance or wait.
5. **Hysteresis hold blocking?**
   With `DEADBAND_HOLD = 1`, this is rare — should commit on the next tick. If you see `desired_on != current_on` in two consecutive `[fan-auto]` ticks but no transition, something is reseting `_fan_hold_counts`.
6. **GPIO is firing but no fan?**
   `pinctrl get <pin>` shows LOW but no relay click → relay board issue: 12V (or 5V) coil supply absent, jumper unseated, or the SunFounder TS0012 needs its enable jumper. **Active-LOW means a floating GPIO at boot can briefly latch ON** — confirmed start state should be HIGH.

### "Fan won't turn off"

1. **Override stuck on?** Check `fan_overrides` table and `no_run_overrides.json`. If an override has no expiry and was never cleared, it'll hold forever.
2. **Did an override just expire?** If it expired but the fan is still on, the hysteresis-reset path may not have fired. Check `[fan]` lines for `reset_auto_hysteresis` after override expiry. The bug class is documented above.
3. **Curve setpoint at this elapsed minute is high?** Curves can have flat-high regions. `cat /run/smartsake/fan_state.json | jq '.zoneN.setpoint_c'`.
4. **A fan rule is firing** — `mode = "rule"`. Check `fan_rules` table. Rules trump auto.
5. **Service crashed mid-cycle.** SIGKILL or power loss leaves the relay coil in its last state. Restart resets via `init_fans()` (HIGH at boot). If the service is still alive but stuck, `journalctl -u smartsake -f` will show whether the loop is still ticking.

### "Fans oscillate / chatter"

1. **Tolerance too small.** With `tolerance_c = 0`, *any* drift across the setpoint flips the fan. Min recommended: 1.0 °C. Set in `zone_config.json["zoneN"]["tolerance_c"]`. Hot-reloads.
2. **TC noise.** TC reads are median-filtered (`TC_FILTER_WINDOW`), but a flapping probe contact can still cause spikes. `journalctl -u smartsake -f | grep -E 'tc|MAX31850'` for read errors. Check probe physical mount.
3. **`DEADBAND_HOLD` too low.** Default = 1 (commits next tick). Bumping to 2 doubles the dwell at the cost of a 10s slower response.

### "Fans on at boot, before any logic runs"

This is a wiring/relay polarity problem, not a software bug.

- **`init_fans()` sets every pin HIGH.** Active-LOW relays interpret HIGH as OFF. So pins-HIGH-at-boot is correct.
- If a relay is ON before `init_fans()` runs (the ~3 second `ExecStartPre=/bin/sleep 3` window), it's because the GPIO is floating LOW *or* the relay board is wired active-HIGH. Confirm the SunFounder TS0012 jumper position. Verify with `pinctrl get` immediately after a fresh boot.

### "Service restart works but power-cycle leaves a fan on"

Expected. SIGKILL/power-loss bypasses the shutdown handler, so the relay coil holds its last energized state. Hard cutoff: kill the relay board's 12V supply, or pull AC. The dashboard `/api/runs/<id>/emergency-stop` endpoint forces all fans OFF via the running service.

### "Looks right in logs but the load isn't switching"

This is downstream of GPIO. Confirm with a multimeter at the relay terminals (NO/NC swap, a dead board), the 120 VAC contactor (some hardware uses a TS0012 → contactor stage), and the fuse on the fan rail.

---

# Part 2 — Load cell calibration

## How it works

Each scale 1–4 has its own HX711 amplifier on a unique `(DAT, CLK)` GPIO pair. `start_sensor_loop()` reads `scale_config.json`, instantiates one `HX711` per configured scale (those with non-null pins), and spawns a daemon thread per scale via `run_hx711_thread`.

### The HX711 thread (every `WEIGHT_INTERVAL_S = 30s`)

```
hot-reload scale_config.json by mtime → push new tare/factor/points into the live HX711 instance
get_weight(samples=10) → median-filtered raw, weight_kg
write to weight_state[scale_id] (in-memory, primary path)
write scale_<id>_data.json (secondary log)
sleep 30s
```

Hot-reload means **edits to `scale_config.json` take effect within ~30s** without service restart. The dashboard calibration API uses this exact path.

### Two calibration modes

- **Single-point** — `tare_offset` (raw with empty cell) + `calibration_factor` (raw delta per gram). Math: `(raw - tare_offset) / calibration_factor = grams`. Falls into this mode when no `calibration_points` array is present.
- **Multi-point** — `calibration_points: [{raw, weight_g, label}, …]`. Requires ≥2 points. Piecewise-linear interp inside the range; nearest-segment slope extrapolated outside. Whenever ≥2 points exist, the server **also** auto-derives legacy `tare_offset` and `calibration_factor` from the min and max points for backwards compat.

### Server endpoints (calibration page)

All wrap their config writes in `_AtomicCfgSection` (RLock + atomic file replace) so parallel calls (e.g. "Calibrate All" firing 4 POSTs at once) can't clobber each other.

| Endpoint | Effect |
|---|---|
| `POST /api/scale-config/<id>/tare` | Read the live raw value, write `tare_offset`. |
| `POST /api/scale-config/<id>/calibrate` | Body `{kg: <known weight>}`. Computes factor from `(raw - tare) / known_weight_g`. Rejects factor < 1e-3. |
| `POST /api/scale-config/<id>/manual-set` | Body `{tare_offset, calibration_factor}`. Direct edit. Drops `calibration_points`. |
| `POST /api/scale-config/<id>/cal-point` | Body `{weight_g, label}`. Reads current raw, appends to `calibration_points`. Once ≥2 points, derives legacy fields. |
| `POST /api/scale-config/<id>/clear-cal-points` | Drops `calibration_points`. Falls back to single-point. |
| `POST /api/scales/calibrate-all` | Splits a known total weight evenly across 4 cells, calibrates each. |

### Raw value sanity

HX711 24-bit signed range is ±8388608. The driver clamps to ±9000000 (a clipped/floating value gets `[SKIP] Rejected bad raw read` and falls out of the average). With 10 samples per read, the median filter rejects values >1.5×IQR from the median (or a min margin of 500). If all 10 reads are bad, `read_average` raises `ValueError("No valid readings -- check wiring")`.

### `_offset` of 0 vs `tare_offset` of 0

A factory-fresh `scale_config.json` has `tare_offset: 0` for unwired scales — that's not "tared", it's "uncalibrated". You can tell by checking `cat scale_config.json | jq '.scales."N".tare_offset'` against the live raw — if they're far apart, this scale was never tared.

---

## Diagnostic command cookbook (load cell)

```bash
# What's wired and what's calibrated?
python3 load_cell_hx711.py --list
# → Scale 1 (Scale 1): pins=5/6 [configured], calibration [single-point]
# → Scale 4 (Scale 4): pins=20/21 [configured], calibration [uncalibrated]

# Live raw + weight, all 4 scales
watch -n 1 'cat /run/smartsake/sensor_latest.json | jq "{w1: .weight_kg_1, w2: .weight_kg_2, w3: .weight_kg_3, w4: .weight_kg_4, raw1: .weight_raw_1, raw2: .weight_raw_2, raw3: .weight_raw_3, raw4: .weight_raw_4}"'

# Or via API (same data path, no jq)
curl -s http://localhost:8080/api/sensor-latest | jq '.weight_kg_1, .weight_raw_1'

# Just the config for one scale
cat scale_config.json | jq '.scales."1"'

# HX711 init + read errors in the live log
journalctl -u smartsake -f | grep -E 'HX711|scale [0-9]'

# Boot log — did each scale init?
journalctl -u smartsake -b | grep -E 'HX711.*initialized|scale [0-9].*calibration'

# Re-tare a single scale (CLI, requires service stopped — both will fight for the GPIO)
sudo systemctl stop smartsake
python3 load_cell_hx711.py --tare --scale 1
sudo systemctl start smartsake

# Single-point cal via CLI (same caveat — stop the service first)
python3 load_cell_hx711.py --calibrate --scale 1

# Multi-point cal via CLI
python3 load_cell_hx711.py --calibrate-multipoint --scale 1

# Smoke test — read each configured scale 10× and print raw + weight
python3 test_scales.py

# Live re-tare via API (service running, no stop needed)
curl -X POST http://localhost:8080/api/scale-config/1/tare

# Live single-point cal via API (place known weight first)
curl -X POST -H 'Content-Type: application/json' \
  -d '{"kg": 2.5}' \
  http://localhost:8080/api/scale-config/1/calibrate

# Manual set (skip the read, type in known-good values)
curl -X POST -H 'Content-Type: application/json' \
  -d '{"tare_offset": 4166, "calibration_factor": 8000}' \
  http://localhost:8080/api/scale-config/1/manual-set

# Clear multi-point curve
curl -X POST http://localhost:8080/api/scale-config/1/clear-cal-points
```

## Symptom → cause decision tree (load cell)

### "Scale shows 0 / never updates"

1. **Is the scale even configured?** `python3 load_cell_hx711.py --list` — if it shows `[not wired]`, `dat_pin`/`clk_pin` are null in `scale_config.json`. Set them, restart service.
2. **Did the HX711 init?** `journalctl -u smartsake -b | grep "HX711 scale 1 initialized"` should be there. If you see `[WARN] Scale 1 failed to init: ...`, the cause is in the message — usually `RPi.GPIO.setup` failing on a reserved pin or `HX711 not responding -- check wiring!`.
3. **Pin conflict.** If you've put a fan relay or another HX711 on a reserved pin, both will fight. Cross-check `fan_gpio.FAN_PINS` and `scale_config.json`. The **GPIO map** in `CLAUDE.md` is authoritative.
4. **Serial console blocking pin 15** (scale 2 CLK). `sudo raspi-config` → Interface → Serial Port → No login shell, **Yes** hardware. Reboot.
5. **Wiring.** Float on DAT (jumper unseated) → driver hits `TimeoutError("HX711 not responding")` after 1 s and the read fails. Check continuity DAT and CLK.

### "Weight is wildly off"

1. **Is the cell tared?** Empty raw should be near `tare_offset`. `cat scale_config.json | jq '.scales."1".tare_offset'` vs `cat /run/smartsake/sensor_latest.json | jq '.weight_raw_1'`. Near-equal under empty load = tared. Far apart = re-tare.
2. **Sign flipped.** If load makes weight go *negative*, the cell's signal A+/A- is swapped. Either swap the wires or accept a negative `calibration_factor` (works fine — math is symmetric).
3. **Factor calibrated against the wrong weight.** Replace via `--calibrate` CLI or the dashboard. Math sanity: `(raw_under_load - tare_offset) / known_weight_grams = factor`. The shipping default `calibration_factor = 8000` is a placeholder for the FX29X 040A — your physical cell will land somewhere around there but rarely exactly.
4. **Multi-point overrides single-point.** If `calibration_points` array exists (≥2 entries), it wins. Check `cat scale_config.json | jq '.scales."1".calibration_points'`. Either delete the array (`/clear-cal-points` endpoint) or recalibrate it.

### "Weight drifts / wanders by hundreds of grams"

1. **HX711 warm-up.** The amp is temperature-sensitive. After power-on, give it 5–10 min before calibrating or trusting weights. Watching `weight_raw_N` in `sensor_latest.json` should show the drift settling.
2. **Mechanical creep.** The 233 FX29X is a strain gauge — under sustained load it can creep ~0.1% over hours. For a 60 kg load, that's ±60 g. Visible in `room-history.html`.
3. **Vibration / cable microphonics.** Unshielded HX711 cabling near the fan motor or the AC contactor will pick up noise. Route HX711 wiring away from the relay board and AC mains. Twist DAT/CLK pairs.
4. **Excitation supply sag.** HX711 is ratiometric, so excitation noise mostly cancels — but if 5V rail is sagging hard (Pi underpowered, weak USB-C supply), you'll see drift correlated with CPU load.

### "Calibrate All split a 4 kg weight, only one scale's cal stuck"

This was the concurrent-write race; fixed by `_AtomicCfgSection`. If you see it again, a regression has slipped in. Look at `_scale_cfg_section` usage in `server.py` — every read-modify-write of `scale_config.json` should go through it.

### "Multi-point cal looks right but `weight_kg` doesn't match the points"

1. **Order matters for the legacy derive.** The server sorts points by `weight_g` and uses min/max to derive `tare_offset` and `calibration_factor`. The interpolation itself uses the full sorted list. So: with 5 well-distributed points, interp is accurate; with 2 points where the heavy weight is `0.1 kg`, the legacy derive is fine but interp is just a single line.
2. **Duplicate raw values.** `set_calibration_points` dedupes by `raw`, keeping the *last* entry per raw. If you logged the same point twice with different weights (typo), the last one wins. Watch the `[WARN]` line in the journal.
3. **Out-of-range loads.** Loads outside the calibrated raw range get extrapolated using the slope of the nearest segment. Calibrate at the edges of your expected use range.

### "Two scales read the same value when only one is loaded"

Mechanical, not electrical. The koji table top is one rigid plate distributing across 4 cells — that's by design. **Center load splits ~25% per cell**. If pressing one corner moves all four cells, the load path is correct. If pressing one corner *also* moves the diagonal corner more than the adjacent ones, the table is twisting — check the housing torque and the cell mounting.

### "HX711 read error: HX711 not responding -- check wiring!"

The driver waits up to 1 s for `DAT` to go LOW (data-ready). If it never does:

1. DAT pin not actually connected to HX711 OUT. Verify with continuity meter.
2. HX711 not powered (5V/GND).
3. The HX711 entered low-power mode — toggling CLK HIGH-then-LOW resets it. The driver does this automatically in `reset()`, but a flaky CLK line means it never lands.
4. Wrong pins assigned in `scale_config.json` (you set DAT to a pin that's actually wired as CLK).

---

# When all else fails

- **Stop the service, run the standalone CLI** — `sudo systemctl stop smartsake; python3 WriteSensors.py`. Stdout goes to your terminal directly, no journal indirection.
- **Walk through one tick by hand** — set a breakpoint or `print` in `evaluate_fan_state`, fire one read with a known TC value, see what the limit-switch decides.
- **Check `test_failure_injection.py`** — it lists the things that have already gone wrong once. If your symptom matches a test scenario, the test name will tell you what was originally fixed and where to look.

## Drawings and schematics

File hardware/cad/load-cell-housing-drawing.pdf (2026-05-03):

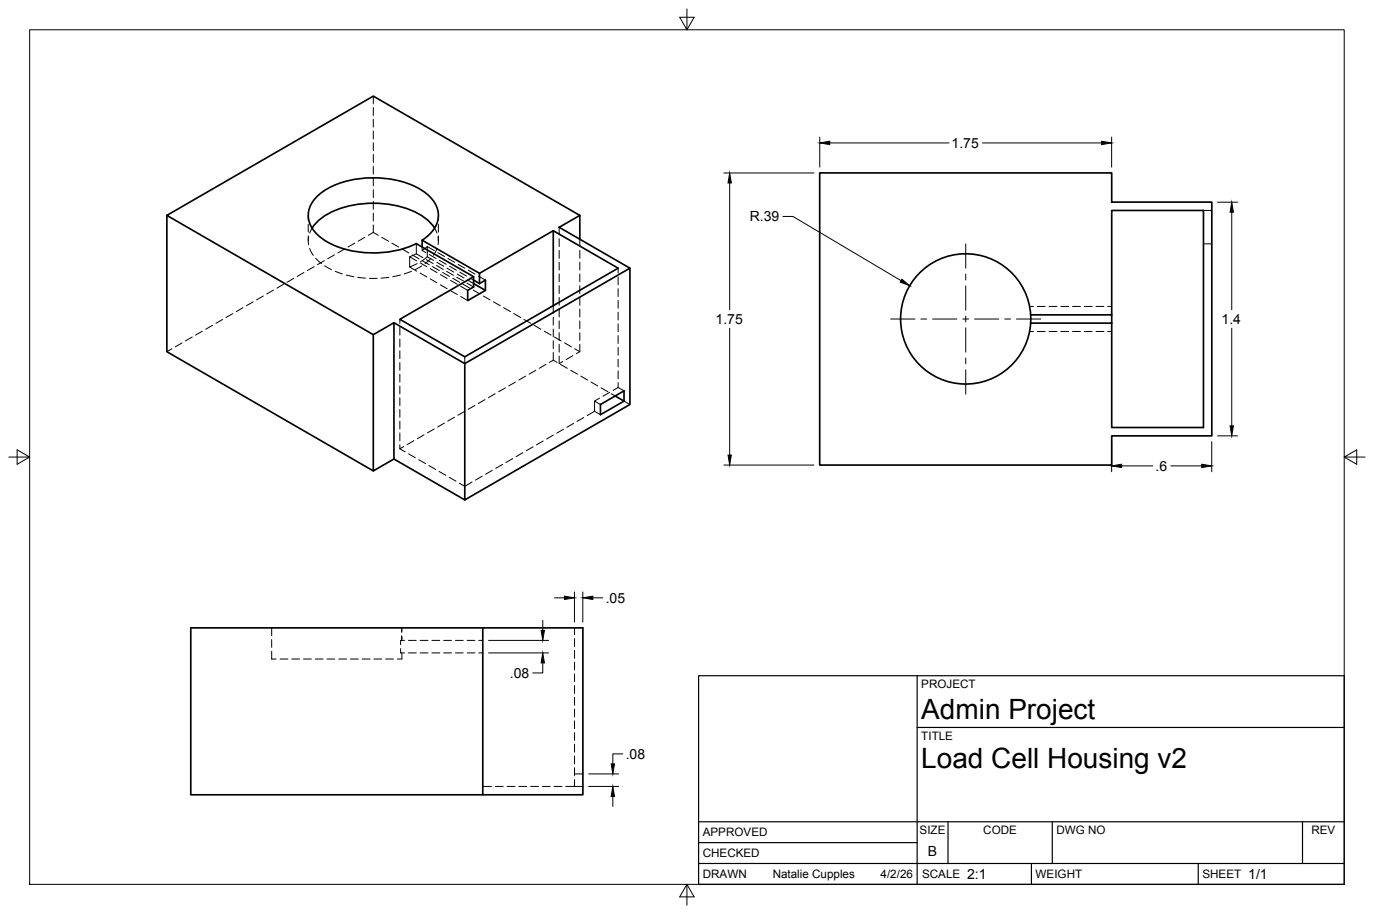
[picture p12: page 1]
SIZE; CODE; DWG NO; REV; Natalie Cupples

PROJECT
Admin Project
Load Cell Housing v2

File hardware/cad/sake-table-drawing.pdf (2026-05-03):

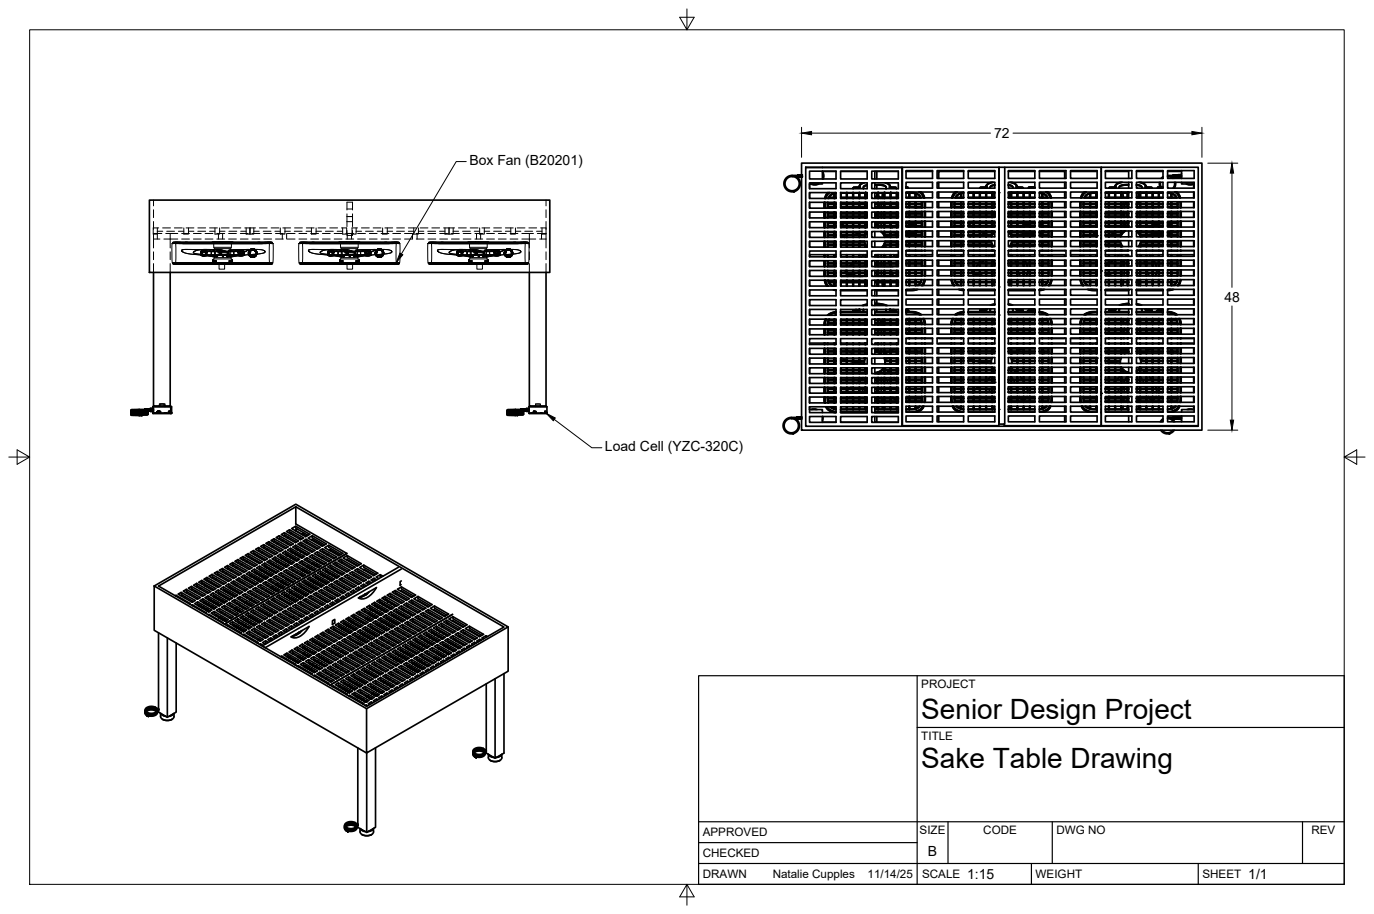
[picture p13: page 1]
SIZE; CODE; DWG NO; REV; Natalie Cupples 11/14/25; Box Fan (B20201)

Load Cell (YZC-320C)

PROJECT
Senior Design Project
Sake Table Drawing

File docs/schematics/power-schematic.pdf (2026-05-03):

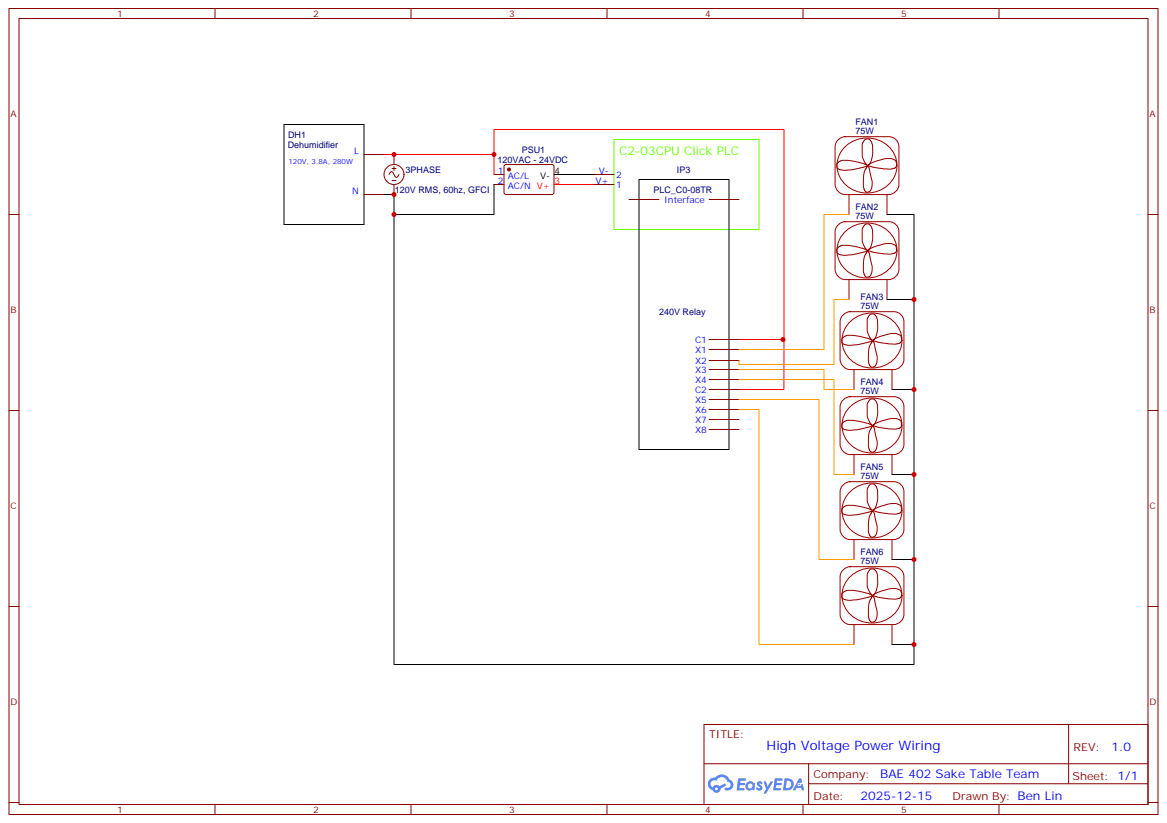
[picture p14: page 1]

Company: BAE 402 Sake Table Team

Drawn By: Ben Lin

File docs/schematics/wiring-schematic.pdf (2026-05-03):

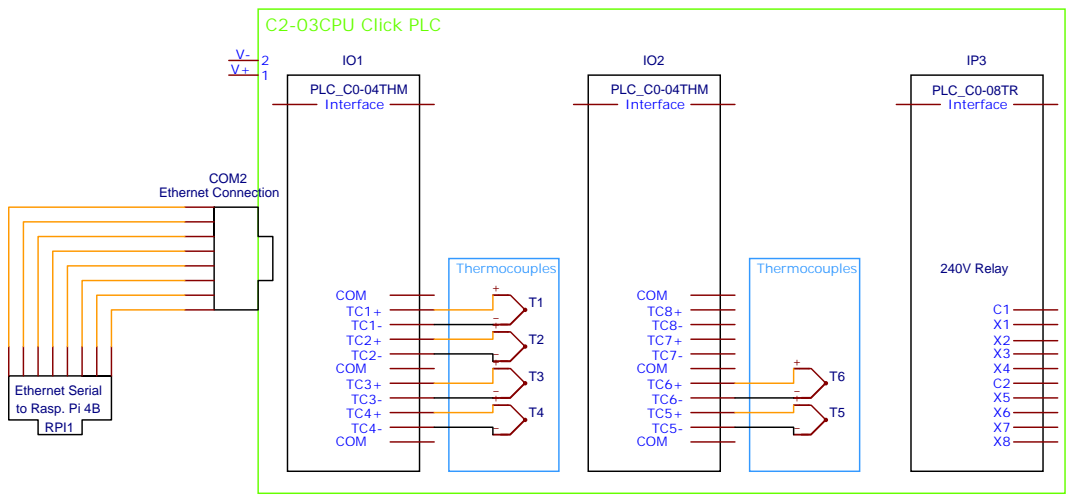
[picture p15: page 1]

Company: BAE 402 Sake Table Team

Drawn By: Ben Lin

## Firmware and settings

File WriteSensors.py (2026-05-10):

import glob
import json
import time
import csv
import os
import shutil
import signal
import statistics
import sys
import threading
from collections import deque
from datetime import datetime, timedelta

import db as sakedb
import fan_gpio

# ── Hardware library imports — guarded so missing libs log a warning and degrade
# gracefully rather than crashing the whole process. ──────────────────────────
MAX_THERMOCOUPLES = 6
_W1_BASE = "/sys/bus/w1/devices"

try:
    from sensors import discover_devices, read_temp_c, format_device_id, MAX_THERMOCOUPLES
    _TC_AVAILABLE = True
except (ImportError, SyntaxError) as _e:
    print(f"[WARN] sensors.py import failed ({_e}) — using built-in 1-Wire fallback")
    _TC_AVAILABLE = False

    def discover_devices():
        """Fallback: scan 1-Wire bus directly."""
        return sorted(glob.glob(f"{_W1_BASE}/3b-*"))[:MAX_THERMOCOUPLES]

    def read_temp_c(device_folder):
        """Fallback: read temperature from w1_slave file."""
        device_file = f"{device_folder}/w1_slave"
        with open(device_file, "r") as f:
            lines = f.readlines()
        if not lines[0].strip().endswith("YES"):
            raise RuntimeError("CRC check failed")
        pos = lines[1].find("t=")
        if pos == -1:
            raise RuntimeError("Temperature data not found")
        return int(lines[1][pos + 2:]) / 1000.0

    def format_device_id(device_folder):
        return os.path.basename(device_folder)

try:
    from load_cell_hx711 import HX711, SAMPLES_PER_READ, load_scale_config, log_weight
    _HX_AVAILABLE = True
except ImportError as _e:
    print(f"[WARN] HX711 libs not available ({_e}) — scale readings disabled")
    _HX_AVAILABLE = False
    def load_scale_config(**kw): return {}

try:
    import board as _board
    import adafruit_sht31d as _adafruit_sht31d
    _SHT_AVAILABLE = True
except ImportError as _e:
    print(f"[WARN] SHT30 libs not available ({_e}) — humidity/env probe disabled")
    _SHT_AVAILABLE = False


CSV_FILE = os.path.join(os.path.dirname(os.path.abspath(__file__)), "sensor_data.csv")
MAX_CSV_ROWS = 8640   # ~24 hrs at 10-second interval

# ── Polling intervals ────────────────────────────────────────────────────────
SENSOR_INTERVAL_S = 10   # TC + SHT30 + fan control + CSV/JSON/DB
WEIGHT_INTERVAL_S = 30   # HX711 thread ADC read cycle


# ── systemd watchdog (sd_notify) ─────────────────────────────────────────────
# Open the NOTIFY_SOCKET once at import time. Each sensor-loop tick pings
# WATCHDOG=1 so systemd's WatchdogSec doesn't SIGABRT the service. No-op when
# not running under systemd.
_NOTIFY_SOCK = None
try:
    _notify_path = os.environ.get("NOTIFY_SOCKET")
    if _notify_path:
        import socket as _socket
        _NOTIFY_SOCK = _socket.socket(_socket.AF_UNIX, _socket.SOCK_DGRAM)
        # Abstract socket: leading '@' or '\0' in path
        _NOTIFY_SOCK.connect("\0" + _notify_path[1:] if _notify_path[0] == "@" else _notify_path)
except Exception as _e:
    print(f"[sd_notify] init skipped: {_e}")
    _NOTIFY_SOCK = None


def _sd_notify(msg):
    if _NOTIFY_SOCK is None:
        return
    try:
        _NOTIFY_SOCK.send(msg.encode("utf-8"))
    except Exception:
        pass

# Cached CSV line count — avoids re-reading the entire file on every write.
# Initialized from disk on first use, then incremented in memory.
_csv_line_count = None

SHT30_TEMP_OFFSET_C = 0.0

# Shared state updated by background HX711 threads, read by main sensor loop.
# Use _weight_lock when reading or writing to prevent torn reads.
import threading as _threading
_weight_lock = _threading.Lock()
weight_state = {
    1: {'kg': None, 'raw': None},
    2: {'kg': None, 'raw': None},
    3: {'kg': None, 'raw': None},
    4: {'kg': None, 'raw': None},
}
_active_run_id = None
_last_db_write_time: float = 0.0
# Tracks the run_id we serviced on the previous loop iteration. Used to
# distinguish "brand-new run" from "resuming the same run after restart"
# even when there was a no-run gap in between (which would otherwise leave
# _active_run_id == None and trick the legacy resuming heuristic).
_last_serviced_run_id = None

# ── Deviation detection state ─────────────────────────────────────────────────
_deviation_tracking = {}
_cached_profile = {"run_id": None, "points": {}, "loaded_at": 0.0}
_PROFILE_CACHE_TTL = 60.0  # re-read DB if curve is swapped mid-run
_threshold_breach_start = {}

DEVIATION_THRESHOLD_C = 2.0
DEVIATION_HOLD_MIN    = 10.0


def invalidate_profile_cache():
    """Force the next evaluate_fan_state call to re-read the target profile from DB.

    Call this from the server when a target curve is assigned or changed so the
    sensor loop picks it up immediately instead of waiting up to 60s.
    """
    _cached_profile["loaded_at"] = 0

# ── TC noise filter ──────────────────────────────────────────────────────────
TC_FILTER_WINDOW = 3          # rolling median over last 3 readings (~30s at 10s cycle)
_tc_history = {}              # {zone: deque(maxlen=TC_FILTER_WINDOW)}


def _tc_filtered(zone, raw_c):
    """Return rolling-median-filtered TC value. Kills single-reading spikes."""
    if raw_c is None:
        return None
    buf = _tc_history.get(zone)
    if buf is None:
        buf = deque(maxlen=TC_FILTER_WINDOW)
        _tc_history[zone] = buf
    buf.append(raw_c)
    return statistics.median(buf)


# ── Limit-switch fan-control constants ───────────────────────────────────────
DEADBAND_HOLD       = 1          # ~10s at 10s cycle — protects relay life
DEFAULT_TOLERANCE_C = 1.0

_BASE_DIR        = os.path.dirname(os.path.abspath(__file__))

# Volatile JSON files go to tmpfs when running under systemd to reduce SD writes.
# systemd's RuntimeDirectory=smartsake creates /run/smartsake/ owned by the service user.
_VOLATILE_DIR    = "/run/smartsake" if os.path.isdir("/run/smartsake") else _BASE_DIR

JSON_FILE        = os.path.join(_VOLATILE_DIR, "sensor_latest.json")
FAN_STATE_JSON   = os.path.join(_VOLATILE_DIR, "fan_state.json")
ZONE_CONFIG_FILE = os.path.join(_BASE_DIR, "zone_config.json")
TC_ZONE_MAP_FILE = os.path.join(_BASE_DIR, "tc_zone_map.json")

_zone_cfg       = {}
_zone_cfg_mtime = 0  # ns precision via os.stat().st_mtime_ns

_tc_zone_map       = {}
_tc_zone_map_mtime = 0

_fan_hold_counts = {z: 0     for z in range(1, 7)}
_fan_on          = {z: False for z in range(1, 7)}
_last_fan_mode            = {z: "none" for z in range(1, 7)}
_last_fan_setpoint        = {z: None   for z in range(1, 7)}
_last_fan_setpoint_source = {z: None   for z in range(1, 7)}  # "curve" | "config" | None
_last_fan_trigger         = {z: None   for z in range(1, 7)}
_last_fan_alarm_level     = {z: None   for z in range(1, 7)}  # "warning" | "critical" | None
_last_fan_alarm_reason    = {z: None   for z in range(1, 7)}

# Tracks zones that had an active in-run (DB-backed) fan override on the
# previous tick. When an override expires between ticks it disappears from
# get_all_fan_overrides, so we use the diff (last - current) to know which
# zones just transitioned back to auto and need their hysteresis cleared —
# mirrors the no-run path in _purge_expired_no_run_overrides.
_last_run_override_zones = set()

# ── No-run manual overrides ──────────────────────────────────────────────────
# When no run is active, users can still manually force fans on/off.
# These overrides are checked by evaluate_fan_state_no_run before auto logic.
# Persisted to a JSON file in the volatile dir so they survive service
# restarts (watchdog, deploys, crashes) but are cleared on full reboot.
# Cleared when a run starts, or when user clicks "Auto".
# Schema: {zone_int: {"action": "on"|"off", "expires_at": iso_str|None}}
_no_run_overrides = {}
_no_run_overrides_lock = threading.Lock()


def _no_run_overrides_path():
    # Persisted to project root (not tmpfs) so a power loss / reboot
    # doesn't silently drop the user's manual fan command. Override
    # toggles are infrequent (clicks, not loop ticks), so SD-card wear
    # is negligible.
    return os.path.join(_BASE_DIR, "no_run_overrides.json")


def _persist_no_run_overrides():
    try:
        path = _no_run_overrides_path()
        tmp = path + ".tmp"
        # Persist with string keys (JSON requirement).
        serializable = {str(z): v for z, v in _no_run_overrides.items()}
        with open(tmp, "w") as f:
            json.dump(serializable, f)
        os.replace(tmp, path)
    except Exception as e:
        print(f"[fan] Could not persist no_run_overrides: {e}")


def _load_no_run_overrides():
    """Load persisted no-run overrides on module import. Drops expired entries."""
    path = _no_run_overrides_path()
    if not os.path.exists(path):
        return
    try:
        with open(path) as f:
            data = json.load(f) or {}
    except Exception as e:
        print(f"[fan] Could not load no_run_overrides ({e}) — ignoring")
        return
    now = datetime.now()
    for k, v in data.items():
        try:
            z = int(k)
        except (TypeError, ValueError):
            continue
        if not isinstance(v, dict):
            continue
        action = v.get("action")
        if action not in ("on", "off"):
            continue
        expires = v.get("expires_at")
        if expires:
            try:
                if datetime.fromisoformat(expires) <= now:
                    continue
            except Exception:
                expires = None
        _no_run_overrides[z] = {"action": action, "expires_at": expires}
    if _no_run_overrides:
        print(f"[fan] Restored {len(_no_run_overrides)} no-run override(s) from disk")


def set_no_run_override(zone, action, duration_minutes=None):
    """Set a manual override for a zone when no run is active.

    duration_minutes=None means "until cleared". A positive integer sets a
    timed override that auto-expires after that many minutes.
    """
    expires_at = None
    if duration_minutes is not None:
        expires_at = (datetime.now() + timedelta(minutes=int(duration_minutes))).isoformat()
    with _no_run_overrides_lock:
        _no_run_overrides[zone] = {"action": action, "expires_at": expires_at}
        _persist_no_run_overrides()


def clear_no_run_override(zone):
    """Clear manual override — zone returns to auto control.

    Also resets the auto hysteresis state for the zone so the auto loop
    re-evaluates from a fresh "fan off" baseline rather than inheriting
    the manual choice. Without this, clicking Auto from a manual ON state
    while the actual temp is in the deadband (between setpoint and trigger)
    would leave the fan running indefinitely because hysteresis preserves
    `_fan_on=True` from the override.
    """
    with _no_run_overrides_lock:
        popped = _no_run_overrides.pop(zone, None) is not None
        if popped:
            _persist_no_run_overrides()
    if popped:
        reset_auto_hysteresis(zone)


def reset_auto_hysteresis(zone):
    """Reset the auto-loop hysteresis state for a zone.

    Called when transitioning from manual override back to auto control
    so the auto loop starts from a fresh "fan off" baseline. The next
    auto evaluation will turn the fan on iff actual temp truly exceeds
    the trigger — matching the user's expectation that "Auto" means
    "let the system decide" rather than "keep doing what I last said".
    """
    if zone in _fan_on:
        _fan_on[zone] = False
    if zone in _fan_hold_counts:
        _fan_hold_counts[zone] = 0


def _purge_expired_no_run_overrides():
    """Drop any expired entries. Called from the fan loop each tick."""
    now = datetime.now()
    with _no_run_overrides_lock:
        expired = []
        for z, ov in _no_run_overrides.items():
            exp = ov.get("expires_at")
            if not exp:
                continue
            try:
                if datetime.fromisoformat(exp) <= now:
                    expired.append(z)
            except Exception:
                expired.append(z)
        for z in expired:
            _no_run_overrides.pop(z, None)
        if expired:
            _persist_no_run_overrides()
    # Reset hysteresis outside the lock so the auto loop re-evaluates from
    # a fresh "fan off" baseline (matches manual-clear behavior). Without
    # this, an expired ON override would leave _fan_on=True and the fan
    # could stay on through the deadband band.
    for z in expired:
        reset_auto_hysteresis(z)


def get_no_run_overrides():
    """Return {zone_int: action_str} for active (non-expired) overrides.

    Kept as the legacy shape so existing callers (server.py /api/fan-state)
    don't need to know about expires_at — that's handled by the fan loop.
    """
    _purge_expired_no_run_overrides()
    with _no_run_overrides_lock:
        return {z: ov["action"] for z, ov in _no_run_overrides.items()}


def get_no_run_overrides_full():
    """Return the full {zone_int: {action, expires_at}} dict."""
    _purge_expired_no_run_overrides()
    with _no_run_overrides_lock:
        return {z: dict(ov) for z, ov in _no_run_overrides.items()}


# Restore persisted overrides on module import so a service restart doesn't
# silently drop the user's manual fan command.
_load_no_run_overrides()


# Alarm thresholds — derived from setpoint + tolerance, no separate UI inputs.
ALARM_WARN_MULT = 1.0   # warning when |actual - setpoint| > tolerance
ALARM_CRIT_MULT = 2.0   # critical when |actual - setpoint| > 2 × tolerance


def _load_target_profile(run_id):
    now = time.time()
    if (_cached_profile["run_id"] == run_id and
            (now - _cached_profile["loaded_at"]) < _PROFILE_CACHE_TTL):
        return _cached_profile["points"]
    rows = sakedb.get_target_profile(run_id)
    pts = [(r["elapsed_min"], r["temp_target"]) for r in rows if r["temp_target"] is not None]
    # _interp_target assumes pts are sorted by elapsed_min ascending. Sort
    # defensively so a curve saved out of order doesn't yield wrong setpoints.
    pts.sort(key=lambda p: p[0])
    shared = {z: pts for z in range(1, 7)} if pts else {}
    _cached_profile["run_id"] = run_id
    _cached_profile["points"] = shared
    _cached_profile["loaded_at"] = now
    return shared


def _interp_target(profile_pts, elapsed_min):
    if not profile_pts:
        return None
    if elapsed_min <= profile_pts[0][0]:
        return profile_pts[0][1]
    if elapsed_min >= profile_pts[-1][0]:
        return profile_pts[-1][1]
    for i in range(len(profile_pts) - 1):
        t0, v0 = profile_pts[i]
        t1, v1 = profile_pts[i + 1]
        if t0 <= elapsed_min <= t1:
            frac = (elapsed_min - t0) / (t1 - t0)
            return v0 + frac * (v1 - v0)
    return None


def _load_zone_config():
    global _zone_cfg, _zone_cfg_mtime
    try:
        mtime = os.stat(ZONE_CONFIG_FILE).st_mtime_ns
        if mtime != _zone_cfg_mtime:
            with open(ZONE_CONFIG_FILE) as f:
                _zone_cfg = json.load(f)
            _zone_cfg_mtime = mtime
            _warn_zone_cfg_outliers(_zone_cfg)
    except Exception:
        if not _zone_cfg:
            _zone_cfg = {"default": {"tolerance_c": DEFAULT_TOLERANCE_C}}
    return _zone_cfg


def _warn_zone_cfg_outliers(cfg):
    """Log warnings when zone config holds out-of-range values.
    Fires once per disk change (driven by the mtime cache above) so it
    won't spam. Doesn't reject — downstream still uses the value, but
    the operator gets a heads-up via the journal."""
    if not isinstance(cfg, dict):
        return
    for key, entry in cfg.items():
        if not isinstance(entry, dict):
            continue
        sp = entry.get("setpoint_c")
        if isinstance(sp, (int, float)) and not (0 <= sp <= 60):
            print(f"[zone-cfg] WARN: {key} setpoint_c={sp} outside 0-60 °C "
                  f"(koji typically 25-40); using as-is")
        tol = entry.get("tolerance_c")
        if isinstance(tol, (int, float)) and tol <= 0:
            print(f"[zone-cfg] WARN: {key} tolerance_c={tol} <= 0 — auto loop "
                  f"will treat zone as always-in-band; alarms disabled")


def _hot_reload_tc_zone_map():
    """Re-read tc_zone_map.json if it changed on disk. Returns the current map dict."""
    global _tc_zone_map, _tc_zone_map_mtime
    try:
        mtime = os.stat(TC_ZONE_MAP_FILE).st_mtime_ns
        if mtime != _tc_zone_map_mtime:
            with open(TC_ZONE_MAP_FILE) as f:
                raw = json.load(f)
            if raw and isinstance(raw, dict):
                new_map = {k: int(v) for k, v in raw.items()}
                if new_map != _tc_zone_map:
                    print(f"[sensors] tc_zone_map.json reloaded: "
                          f"{', '.join(f'{cid[:8]}…→z{ch}' for cid, ch in sorted(new_map.items(), key=lambda x: x[1]))}")
                _tc_zone_map = new_map
            _tc_zone_map_mtime = mtime
    except (FileNotFoundError, json.JSONDecodeError, ValueError):
        pass
    return _tc_zone_map


def _zone_tolerance(zone):
    # Defense in depth: _load_zone_config has its own try/except + cached
    # fallback, so it shouldn't raise. If a future regression breaks that
    # contract, swallow here so the auto loop keeps running on defaults.
    try:
        cfg = _load_zone_config()
    except Exception:
        cfg = {}
    default = cfg.get("default", {})
    # Resolve in order: zone-specific tolerance → default block tolerance →
    # module constant. Previously a partial zone entry (e.g. setpoint only)
    # silently shadowed the user-defined default block tolerance because the
    # zone dict won out wholesale.
    zone_cfg = cfg.get(f"zone{zone}", {}) or {}
    val = zone_cfg.get("tolerance_c", default.get("tolerance_c", DEFAULT_TOLERANCE_C))
    try:
        return float(val)
    except (TypeError, ValueError):
        return DEFAULT_TOLERANCE_C


def _zone_setpoint_override(zone):
    try:
        cfg = _load_zone_config()
    except Exception:
        cfg = {}
    v = cfg.get(f"zone{zone}", {}).get("setpoint_c")
    if v is None:
        v = cfg.get("default", {}).get("setpoint_c")
    if v is None:
        return None
    try:
        return float(v)
    except (TypeError, ValueError):
        # Typo'd setpoint (e.g. "thirty") used to crash the fan loop on
        # every tick. Silently treat as "no setpoint" so the zone falls
        # back to no-action — operator notices via the dashboard's
        # "No setpoint configured" badge.
        return None


# Two-point calibration sanity limits.
# Slope must be within 20% of unity (0.8–1.2) — larger deviations indicate
# a wiring/probe problem, not a calibration issue.
TC_CAL_SLOPE_MIN = 0.8
TC_CAL_SLOPE_MAX = 1.2
# The correction at 50°C must not shift the reading by more than 10°C.
TC_CAL_MAX_CORRECTION_AT_50 = 10.0
# Legacy single-point offset cap (backward compat).
TC_OFFSET_MAX_ABS_C = 5.0


def _zone_tc_correct(zone, raw_c):
    """Apply per-zone thermocouple calibration and return the corrected temperature.

    Priority:
      1. Two-point linear calibration (cal_slope + cal_intercept) — most accurate.
      2. Legacy single-point offset (offset_c) — backward compatible fallback.
      3. No calibration — returns raw_c unchanged.
    """
    cfg = _load_zone_config()
    zcfg = cfg.get(f"zone{zone}", {})

    # ── Two-point calibration ───────────────────────────────────────────────
    slope = zcfg.get("cal_slope")
    intercept = zcfg.get("cal_intercept")
    if slope is not None and intercept is not None:
        try:
            slope = float(slope)
            intercept = float(intercept)
        except (TypeError, ValueError):
            slope = intercept = None
        if slope is not None and intercept is not None:
            # NaN guard
            if slope != slope or intercept != intercept:
                return raw_c
            # Sanity: slope must be 0.8–1.2
            if not (TC_CAL_SLOPE_MIN <= slope <= TC_CAL_SLOPE_MAX):
                return raw_c
            corrected = slope * raw_c + intercept
            # Sanity: correction at 50°C must not exceed ±10°C
            if abs((slope * 50.0 + intercept) - 50.0) > TC_CAL_MAX_CORRECTION_AT_50:
                return raw_c
            return corrected

    # ── Legacy single-point offset fallback ─────────────────────────────────
    v = zcfg.get("offset_c")
    if v is None:
        return raw_c
    try:
        v = float(v)
    except (TypeError, ValueError):
        return raw_c
    if v != v:  # NaN guard
        return raw_c
    if abs(v) > TC_OFFSET_MAX_ABS_C:
        return raw_c
    return raw_c - v


def _classify_alarm(actual, setpoint, tolerance):
    """Return (level, reason) for the given temp/setpoint/tolerance triple.

    level: "critical" | "warning" | None
    reason: short human-readable string, or None.
    """
    if actual is None or setpoint is None or tolerance is None or tolerance <= 0:
        return None, None
    diff = actual - setpoint
    abs_diff = abs(diff)
    direction = "above" if diff > 0 else "below"
    if abs_diff > ALARM_CRIT_MULT * tolerance:
        return "critical", (
            f"{abs_diff:.1f}°C {direction} setpoint "
            f"(>{ALARM_CRIT_MULT:g}× tolerance)"
        )
    if abs_diff > ALARM_WARN_MULT * tolerance:
        return "warning", (
            f"{abs_diff:.1f}°C {direction} setpoint "
            f"(>{ALARM_WARN_MULT:g}× tolerance)"
        )
    return None, None
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

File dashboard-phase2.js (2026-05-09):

/* dashboard-phase2.js — Phase 2 feature layer for SmartSake dashboard
 *
 * Depends on globals set by dashboard.html's inline IIFEs:
 *   window._runId            — active run id (int)
 *   window._tempChart        — Chart.js instance for temperature chart
 *   window._envChart         — Chart.js instance for env (humidity) chart
 *   window._weightChart      — Chart.js instance for weight chart
 *   window._sampleElapsedMin — latest elapsed_min value pushed to live charts
 *   window._chartLabels      — shared elapsed-minute labels array (live temp chart)
 *
 * All chart updates use chart.update('none') for Pi 4B performance.
 */

/* ── 1. Stage Marker IIFE ───────────────────────────────────────────────────── */
// Shared HTML-escape helper used across the IIFE modules below.
// Server-side input validation (server.py) already rejects HTML metachars in
// run names + event labels, but we escape on render too as defense in depth.
function escHtmlPhase2(s) {
  if (s == null) return '';
  return String(s).replace(/&/g, '&amp;').replace(/</g, '&lt;').replace(/>/g, '&gt;')
                  .replace(/"/g, '&quot;').replace(/'/g, '&#39;');
}

(function stageMarkerModule() {
  "use strict";

  const KOJI_STAGES = [
    { label: "Hiki-komi",        color: "#6c8ebf" },
    { label: "Kiri-kaeshi",      color: "#82b366" },
    { label: "Naka-shigoto",     color: "#d79b00" },
    { label: "Shimai-shigoto",   color: "#ae4132" },
  ];

  let _markers = [];          // [{id, label, elapsed_min}]
  let _pendingSave = false;

  // Inline Chart.js plugin — draws vertical dashed lines + rotated labels
  const stageMarkerPlugin = {
    id: "stageMarkers",
    afterDraw(chart) {
      if (!_markers.length) return;
      const { ctx, scales, chartArea } = chart;
      const xScale = scales.x;
      if (!xScale || !chartArea) return;

      // Find pixel for an elapsed_min value in the category scale
      const elapsedMins = window._chartElapsedMins || [];
      function elapsedToPx(em) {
        if (!elapsedMins.length) return null;
        let bestIdx = 0, bestDist = Infinity;
        for (let i = 0; i < elapsedMins.length; i++) {
          const d = Math.abs(elapsedMins[i] - em);
          if (d < bestDist) { bestDist = d; bestIdx = i; }
        }
        const lbl = (chart.data.labels || [])[bestIdx];
        return lbl != null ? xScale.getPixelForValue(lbl) : null;
      }

      ctx.save();
      _markers.forEach(m => {
        const color = (KOJI_STAGES.find(s => s.label === m.label) || {}).color || "#888";
        const xPx = elapsedToPx(m.elapsed_min);
        if (xPx == null || xPx < chartArea.left || xPx > chartArea.right) return;

        ctx.beginPath();
        ctx.setLineDash([4, 3]);
        ctx.strokeStyle = color;
        ctx.lineWidth = 1.5;
        ctx.moveTo(xPx, chartArea.top);
        ctx.lineTo(xPx, chartArea.bottom);
        ctx.stroke();
        ctx.setLineDash([]);

        // Rotated label
        ctx.save();
        ctx.translate(xPx - 3, chartArea.top + 6);
        ctx.rotate(-Math.PI / 2);
        ctx.fillStyle = color;
        ctx.font = "10px sans-serif";
        ctx.textAlign = "left";
        ctx.fillText(m.label, 0, 0);
        ctx.restore();
      });
      ctx.restore();
    },
  };

  function _registerPlugin() {
    const chart = window._tempChart;
    if (!chart) return;
    if (!chart.config.plugins) chart.config.plugins = [];
    // Avoid double-registration
    if (!chart.config.plugins.find(p => p.id === "stageMarkers")) {
      chart.config.plugins.push(stageMarkerPlugin);
    }
  }

  function _loadMarkers() {
    const runId = window._runId;
    if (!runId) return;
    fetch(`/api/runs/${runId}/events`)
      .then(r => r.json())
      .then(data => {
        _markers = Array.isArray(data) ? data : [];
        _renderMarkerList();
        const chart = window._tempChart;
        if (chart) chart.update("none");
      })
      .catch(() => {});
  }

  function _addMarker(label, elapsed_min) {
    if (_pendingSave) return;
    _pendingSave = true;
    const runId = window._runId;
    fetch(`/api/runs/${runId}/events`, {
      method: "POST",
      headers: { "Content-Type": "application/json" },
      body: JSON.stringify({ label, elapsed_min, event_type: "stage" }),
    })
      .then(r => r.json())
      .then(() => _loadMarkers())
      .catch(() => {})
      .finally(() => { _pendingSave = false; });
  }

  function _deleteMarker(eventId) {
    const runId = window._runId;
    fetch(`/api/runs/${runId}/events/${eventId}`, { method: "DELETE" })
      .then(() => _loadMarkers())
      .catch(() => {});
  }
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

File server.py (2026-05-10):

"""
SmartSake Flask server (API + static files).

Start with:  python server.py
Default port: 8080

When run directly (python server.py), starts the sensor loop as a background
thread.  When imported by gunicorn, the sensor loop must run separately via
smartsake-sensors.service to avoid duplicate loops across workers.
"""

import json
import os
import re
import shutil
import threading
import time
from flask import Flask, jsonify, request, send_from_directory, abort

import db
import fan_gpio

BASE_DIR            = os.path.dirname(os.path.abspath(__file__))

# Volatile JSON files live on tmpfs when running under systemd (RuntimeDirectory=smartsake).
# Falls back to BASE_DIR in dev / non-systemd environments.
_VOLATILE_DIR       = "/run/smartsake" if os.path.isdir("/run/smartsake") else BASE_DIR

SENSOR_JSON         = os.path.join(_VOLATILE_DIR, "sensor_latest.json")
FAN_STATE_JSON      = os.path.join(_VOLATILE_DIR, "fan_state.json")
SENSOR_STATUS_JSON  = os.path.join(_VOLATILE_DIR, "sensor_status.json")
ZONE_CONFIG_FILE    = os.path.join(BASE_DIR, "zone_config.json")
SCALE_CONFIG_FILE   = os.path.join(BASE_DIR, "scale_config.json")
TC_ZONE_MAP_FILE    = os.path.join(BASE_DIR, "tc_zone_map.json")

app = Flask(__name__, static_folder=BASE_DIR, static_url_path="")

# ── Mtime-cached JSON file reader ────────────────────────────────────────────
_json_cache = {}  # path -> (mtime, data)

def _read_json_cached(path):
    """Read a JSON file, returning cached data if the file hasn't changed.

    Uses st_mtime_ns (nanosecond precision) to avoid the 1s-resolution
    blind spot on ext4 — back-to-back writes within the same second
    would otherwise look unchanged and serve stale data.
    """
    try:
        mtime = os.stat(path).st_mtime_ns
    except OSError:
        return {}
    cached = _json_cache.get(path)
    if cached and cached[0] == mtime:
        return cached[1]
    try:
        with open(path) as f:
            data = json.load(f)
        _json_cache[path] = (mtime, data)
        return data
    except Exception:
        return {}

# ── Direct 1-Wire bus reader (fallback when sensor loop hasn't populated TCs) ─
_W1_BASE = "/sys/bus/w1/devices"

def _read_tc_from_bus():
    """Read all probes from the 1-Wire bus and return as {"TC1": temp, ...}.

    Uses tc_zone_map.json for zone assignment if available, otherwise
    auto-assigns probes to zones 1-6 in discovery order.
    """
    import glob as _glob
    result = {}
    try:
        with open(TC_ZONE_MAP_FILE) as f:
            zone_map = {k: int(v) for k, v in json.load(f).items()}
    except Exception:
        zone_map = {}

    probes = sorted(_glob.glob(f"{_W1_BASE}/3b-*"))
    used_zones = set(zone_map.values())
    next_zone = 1

    for dev_path in probes:
        device_id = os.path.basename(dev_path)
        # Determine zone: mapped or auto-assign
        if device_id in zone_map:
            zone = zone_map[device_id]
        else:
            while next_zone in used_zones and next_zone <= 6:
                next_zone += 1
            if next_zone > 6:
                continue
            zone = next_zone
            used_zones.add(zone)
            next_zone += 1

        # Read temperature
        try:
            slave_file = os.path.join(dev_path, "w1_slave")
            with open(slave_file, "r") as f:
                lines = f.readlines()
            if lines[0].strip().endswith("YES"):
                pos = lines[1].find("t=")
                if pos != -1:
                    result[f"TC{zone}"] = int(lines[1][pos + 2:]) / 1000.0
        except Exception:
            pass

    return result


# ── Database init + run resume ────────────────────────────────────────────────
db.init_db()
_stale = db.get_active_run()
if _stale:
    # Don't mark as crashed — sensor loop will resume recording to this run.
    # Runs are only ended explicitly via the dashboard 'End Run' button.
    print(f"[startup] Active run '{_stale['name']}' (id={_stale['id']}) found — will resume recording.")

# Close each request's thread-local DB connection after the response is sent.
# Flask's dev server creates a new thread per request; without this, stale
# connections accumulate until the thread is garbage-collected.
@app.teardown_appcontext
def _teardown_db(exc):
    db.close_conn()

# Sensor loop is started in __main__ block below (safe for single-process mode).
# Do NOT start it at module level — gunicorn workers would each spawn their own loop.


# ── Static pages ──────────────────────────────────────────────────────────────

@app.route("/")
def index():
    return send_from_directory(BASE_DIR, "home.html")

_SAFE_EXTENSIONS = {
    '.html', '.css', '.js', '.json', '.map',
    '.png', '.jpg', '.jpeg', '.gif', '.svg', '.ico', '.webp',
    '.woff', '.woff2', '.ttf', '.eot',
    '.csv',
}

@app.route("/<path:filename>")
def static_files(filename):
    ext = os.path.splitext(filename)[1].lower()
    if ext not in _SAFE_EXTENSIONS:
        abort(403)
    # Block access to sensitive JSON configs
    base = os.path.basename(filename).lower()
    if base in ('scale_config.json', 'zone_config.json', 'sensor_status.json'):
        abort(403)
    return send_from_directory(BASE_DIR, filename)


# ── Live sensor feed ──────────────────────────────────────────────────────────
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

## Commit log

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2026-03-23 Add SQLite storage, Flask API, home screen, and mode-aware dashboard
    - db.py: SQLite module (runs, sensor_readings, target_profiles, zone_notes)
    - server.py: Flask app replacing SimpleHTTPServer, exposes /api/* routes
    - requirements.txt: flask dependency
    - WriteSensors.py: drops HTTP thread, writes readings to DB when a run is active
    - home.html: run selector — new run, resume active/crashed run, browse history
    - dashboard.html: index.html renamed + mode-aware (live vs replay), loads
    historical readings from API, wires End Run to /api/runs/<id>/end
    - zone1-6.html: notes saved/loaded via /api/runs/<id>/zones/<n>, read-only
    in replay mode, falls back to localStorage when no run id in URL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
    [WriteSensors.py, db.py, server.py]
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2026-03-23 feat: replace random simulator with live sensor poller and normalize API response
    - dashboard.html: swap wet-bulb random simulator for a real /api/latest poller
    that runs every 3 s; feeds pushSensorSample(), BroadcastChannel, and localStorage
    with actual TC readings; adds zone-temp colour classes (cold/ok/warm/hot);
    downsample historical readings to 300 points for chart performance; start-run
    modal now POSTs to /api/runs and redirects with run ID
    - server.py: normalize sensor_latest.json nested structure (thermocouples/sht30)
    into flat tc1–tc6/humidity/sht_temp keys matching DB column names; add unit
    conversion for kg→lbs scale data; fan keys included as null placeholders
    [server.py]
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2026-03-25 feat: Phase 1 — replace dark side panel with bubbly inline zone detail card
    - db.py: add fan_overrides table (upsert per zone, optional expiry) with
    set/get/get_all/clear functions; add index on run_id
    - server.py: add GET /fan-overrides, POST and DELETE /zones/<z>/fan
    with input validation (zone 1-6, action on/off, positive duration)
    - styles.css: remove .zone-panel* dark slide-in styles; add
    .zone-detail-card* bubbly card (white bg, #e1e1e6 border, 8px radius);
    update .layout--home grid to 3 rows so card slots between zone buttons
    and notes without affecting right-column charts
    - dashboard.html: replace fixed side panel HTML with inline card HTML
    after zone grid; rewrite zone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
    [db.py, server.py]
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2026-03-26 feat: zone modals, chart bg colors, target curves, wet-bulb fix, temp chart layout
    UI changes:
    - Zone detail opens as modal overlay (same-page breakout) instead of
    navigating to zone1-6.html; backdrop-click and ESC close it
    - Remove per-zone notes from zone card (notes live only in notes-wrap)
    - Remove Target buttons from env/weight chart headers; move humidity and
    weight target inputs into Settings modal under "Run targets" section
    - Add chart background color pickers to Settings modal (persisted in
    localStorage via getSakeSettings)
    - Temperature chart: fix half-size layout by switching from 2-column CSS
    grid to flex-column so header, legend, chips, and toolbar stack above
    the can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
    [WriteSensors.py]
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2026-03-30 feat: add curves.html curve builder + fix run targets
    - Add standalone curves.html page with Chart.js visual editor for
    building and saving reference temperature curves per zone
    - Curves library panel lists saved curves with edit/delete/apply actions
    - Live chart preview updates as table values are entered
    - Apply button sends curve to active run via POST /api/runs/.../target/from-curve/...
    - Link to curves.html added to home.html Tools panel
    - Fix PUT /humidity-targets to accept both min/max and target_min/target_max
    field names (same fix already applied to /weight-targets)
    - Fix openSettings event listener binding so monkey-patch pre-fill fires
    when settings modal opens (use closure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
    [server.py]
2026-03-30 feat: UI improvements — single-temp curve builder, header fix, env chart, CSV export, zone legend, arcade modal
    - Curve builder: replaced 6-zone temp columns with single shared temperature
    - Fixed header overlapping content (added padding-top clearance)
    - Removed humidity/weight run targets from settings modal
    - Fixed environment graph rendering with flex-column layout
    - Fixed CSV export: added zone notes, use server-side export on run end
    - Added zone temperature state color legend (in range/warm/hot/cold)
    - Replaced pong modal with Void Sake Co. Arcade placeholder
    https://claude.ai/code/session_01VKSkjXXkVbzq1kGaxtJ9YL
    [server.py]
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2026-04-09 feat: add PID fan control system with dashboard mode badges
    - WriteSensors.py: integrate PID controller as tier-3 fan control
    (priority: manual override > rules > PID auto-control)
    - Discrete PID with anti-windup integral clamp (±20)
    - Deadband (±0.5°C) + hold (3 ticks) prevents chattering
    - Gains loaded from pid_config.json with hot-reload on file change
    - Writes fan_state.json with per-zone state/mode/setpoint/pid_out
    - server.py: add GET /api/fan-state, GET/POST /api/pid-config endpoints;
    /api/latest now populates fan1-6 from fan_state.json
    - dashboard.html: add fan ON/OFF + mode (PID/MAN/RULE) badges to all
    6 zone cards; fetchFanState() polls /api/fan-state every 5 s
    - p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
    [pid_config.json]
2026-04-10 refactor: shared sensor module, HX711 thread integration, live JSON fetch
    - Extract sensors.py shared module; WriteSensors.py and max31850_read.py
    now import from it — eliminates ~60 lines of duplicated sensor code
    - Fold HX711 load cell into WriteSensors.py as a daemon thread; weight_kg
    included in sensor_latest.json so the dashboard has one data source
    - Fix double-read bug: HX711.get_weight() returns (weight, raw_avg) tuple
    eliminating the redundant read_average() call (15 reads → 10)
    - Atomic JSON writes via os.replace() to prevent corrupt reads on power loss
    - CSV rotation at 43,200 rows (~24h at 2s interval)
    - import json moved to module top in WriteSensors.py
    - index.html: r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
    [WriteSensors.py, load_cell_hx711.py, max31850_read.py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]
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2026-04-10 feat: SQLite historian — per-run time-series logging, hourly aggregation, CSV export
    - historian.py: Historian class wraps SQLite (sake_history.db) with:
    - runs table (id, name, started_at, ended_at, notes)
    - readings table — all TC/SHT/weight/zone fields per 2-second tick
    - hourly_stats view — AVG/MIN/MAX per TC per hour
    - start_run / end_run / log_reading / export_run_csv methods
    - _write_report: on end_run, writes run_N_name_date.csv with hourly summary appended
    - get_active_run: resumes logging if Pi reboots mid-run
    - Thread-safe via threading.Lock; atomic writes via 'with self.conn'
    - WriteSensors.py: imports Historian; initializes on startup (resumes if run active);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
    [WriteSensors.py, historian.py]
2026-04-11 feat: UI overhaul — design system, theme engine, drag-to-reorder widgets
    - Full CSS rewrite with Inter font, CSS custom properties, consistent
    radius/shadow/transition tokens, spring cubic-bezier on all interactions
    - 4 theme presets (Default, Dark, Sake, Minimal) + custom color picker;
    persisted to localStorage; dark theme covers Chart.js surfaces and all
    formerly hardcoded grays via --color-bg-subtle/tinted
    - Drag-to-reorder for chart cards and zone cards; order saved to localStorage
    - Slide-in settings panel with gear FAB; edit mode banner + dashed outlines
    - Sticky header bar replaces absolute-positioned layout hack; datetime and
    start/end run button inline in header-actions
    -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
    [customize.js]
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2026-04-14 feat: hardware readiness — multi-scale, relay fix, systemd, health gate, calibration, watchdog, backup
    Scale/sensor:
    - 4x HX711 load cell support via scale_config.json (config-driven pins + calibration)
    - Per-scale calibration CLI: --calibrate/--tare/--list --scale N
    - SHT30 offset calibration via calibrate_sht30.py + scale_config sensors key
    - TC zone persistence: tc_zone_map.json survives reboots/reconnects
    Relay/fan:
    - fan_gpio: active-LOW polarity fix (SunFounder TS0012), boot state HIGH
    - FAN_PINS filled in {1:17, 2:27, 3:22, 4:23, 5:24, 6:25}
    - pid_controller.py deleted (dead code)
    Analytics:
    - Combined weight total across 4 scales (COALESCE) in all analytics queries
    - weight_total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
    [WriteSensors.py, backup_db.py, calibrate_sht30.py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]
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2026-04-20 style: standardize header banner across all pages + settings modal rewrite
    - zone1–6: add class="header" so pages inherit sticky/surface/shadow styles
    - history: replace .page-header with canonical header structure (logo + title + settings-btn)
    - room-history: replace .rh-header with canonical structure; range buttons + clock + nav in .header-right; remove dead .rh-header/.rh-brand/.rh-header-right CSS
    - curves: rename title "SmartSake" → "Curves"
    - dashboard/customize.js: settings rewritten from sliding panel to modal-overlay; theme storage unified to localStorage['ss-theme']; THEMES.default removed
    - styles.css: compact header layout rules, weight chart expand support
    - mock_server.py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
    [customize.js, mock_server.py]
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2026-04-21 fix(a11y): Batch 4C+4D — modal ARIA roles, is-open pattern, theme-aware weight chart
    - Add role="dialog" aria-modal="true" to all 13 modals across dashboard.html, index.html, and customize.js (dynamically created modal)
    - Remove hidden attr from zone-detail; switch openCard/closeCard from card.hidden to classList.add/remove('is-open')
    - Convert all index.html modal JS from style.display='flex/none' to classList.add/remove('is-open') for start, end, set-temp, recovery, and pong modals
    - Add backdrop click + Escape handlers to pong modal (previously missing)
    - Update Escape key checks from style.display==='flex' to classList.contains('is-open')
    - Add brand key to getThemeColors(); replace ha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
    [customize.js]
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2026-04-22 fix: temp-state colors for all themes, zone setpoint tracking, dashboard deviation fixes
    - Apply correct light/dark temp-state CSS vars per theme instead of relying on data-theme=dark only
    - Track zone setpoints in fan polling module and expose via getZoneSetpoints()
    - Dashboard deviation color logic cleanup
    - mock_server.py and styles.css updates
    [customize.js, mock_server.py]
2026-04-22 feat: replace mock curve with realistic 48h ginjo koji profile (all 6 zones)
    - MOCK_TARGET now uses correct temp1_target–temp6_target field names
    - Full 9-point ginjo curve: inoculation → kiri-kaeshi → naka-shigoto → shimai-shigoto → cool-down (28→41→34°C over 48h)
    - Per-zone offsets: center zones (1–2) +0.5°C, edge zones (5–6) −0.5°C
    - MOCK_ZONE_SETPOINTS now reflect curve position at 18h (naka-shigoto, ~36.5°C)
    - Oscillating sensor temps centered on per-zone setpoint for realistic color states
    - Added Mugi Koji / Shochu (44h) as second reference curve
    - _koji_curve() helper generates rows for any offset list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
    [mock_server.py]
2026-04-22 fix: make target guide curve visible on main dashboard chart
    - Target line color: muted text2 gray → amber rgba(255,220,80,0.85) — visible on any theme
    - borderWidth: 1.5 → 2
    - borderDash: [8,5] with segment fallback for Chart.js 4 compat
    - order: -1 to draw on top of zone lines
    - Applied consistently to both main chart and expanded modal chart
    [mock_server.py]
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2026-04-28 chore: move unreferenced files to archive/
    Files not imported by server.py / WriteSensors.py and not part of the
    production runtime. Preserves full git history via rename tracking.
    - mock_server.py + restart-mock.bat — dev-only mock server
    - max31850_read.py — standalone MAX31850 thermocouple test
    - test_hardware.py — standalone hardware diagnostics
    - calibrate_sht30.py — standalone SHT30 calibration utility
    - historian.py — superseded by db.py, no longer imported
    - smartsake-sensors.service + smartsake-server.service (root) — duplicated
    by the canonical copies in systemd/
    [calibrate_sht30.py, historian.py, max31850_read.py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]
2026-04-28 feat: tolerance controls, fan trigger display, and backend updates
    - zone1-6.html: add tolerance input/apply control; rename PID output
    chip to fan trigger (°C); update JS refs accordingly
    - server.py / db.py / WriteSensors.py: associated backend updates
    - home.html / curves.html: minor UI updates
    - zone_config.json: add zone config file
    [WriteSensors.py, db.py, server.py]
2026-04-28 fix: single-process sensor+server — no WiFi, no two-process requirement
    Problems found in audit:
    - Chart.js was CDN-only (already fixed), but sensors still didn't work
    - sensors.py had top-level `import board` / `import adafruit_sht31d` that
    crash-killed the entire process if those libs aren't installed
    - WriteSensors.py required running as a SEPARATE process alongside server.py;
    if only server.py ran, zero sensor data ever reached the DB
    - No graceful degradation if any hardware library was missing
    - sensors.py: guard board/adafruit_sht31d imports with try/except so
    the process starts even when those libs are absent
    - WriteSensors.py: guard all hardware imports (TC, HX711,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
    [WriteSensors.py, sensors.py, server.py]
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2026-04-29 feat: lock thermocouples to static zone IDs, refuse boot on bad map
    Replace silent auto-assign-on-discovery with a strict loader that
    validates tc_zone_map.json (no dupes, channels exactly 1..6, all six
    zones present). Sensor loop now refuses to start until the map is
    valid and warns once per unknown probe ID seen on the bus rather
    than mutating the map.
    Add scripts/identify_tcs.py: interactive walkthrough that heats each
    probe in turn to capture the rising ROM ID and writes a clean map.
    Also supports --monitor (live readings) and --check (validate map).
    CONTROLS.txt updated with the new (re)build flow.
    [WriteSensors.py]
2026-04-29 feat: import single CSV into curve builder with 5-min zone averaging
    Refactor generate_curve_from_runs to use a pure bucket-averaging
    helper so the same logic works for DB-sourced runs and CSV input.
    Add parse_curve_csv() — tolerant of run-export, live writer, and
    generic elapsed_min/TC1..TC6 headers; treats ERROR/blank/NaN as
    None; derives elapsed_min from the first row's timestamp when no
    elapsed column is present.
    Add POST /api/reference-curves/generate-from-csv (multipart file
    or JSON csv_text). 25 MB cap, 5..360 min bucket validation. Add
    "Import CSV" panel to curves.html that reuses the existing preview
    chart and Save flow. Add 5-min option to the existing batches
    bucket dropdown.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
    [db.py, server.py]
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2026-04-29 fix(hw): correct fan GPIO pin map to match physical table wiring
    Reverse the zone→GPIO mapping (zone 1 was on GPIO 17, now on 25;
    zone 6 was on GPIO 25, now on 27) to match how the relays are
    actually wired to the Pi on the production table.
    [fan_gpio.py]
2026-04-29 fix: zone setpoint locked even when no curve was driving it
    WriteSensors set _last_fan_mode='limit' whenever any setpoint was in
    effect — curve OR zone_config fallback — so the dashboard zone modal
    treated every saved manual setpoint as curve-driven and locked the
    input on next render. Once a setpoint hit zone_config, it could
    never be edited again from the UI.
    Track setpoint provenance separately as _last_fan_setpoint_source
    ('curve' | 'config' | None) and expose it in fan_state.json.
    Frontend (separate commit) now keys read-only on source==='curve'
    instead of mode==='limit'.
    Also: validate setpoint_c on POST /api/zone-config (number, 0..60,
    not a bool) and add the new field to the de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
    [WriteSensors.py, server.py]
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2026-04-29 feat: derive zone alarms from setpoint + tolerance, drop the dead inputs
    The four per-zone alarm threshold inputs (warn/crit high/low) on the
    zone-detail modal were never wired to anything — Apply was disabled,
    no save endpoint, no load logic, and the alarm banner that would
    have surfaced their result was hard-coded to display:none. The
    zone-card warn/crit class loop on home/index also read alarm_level
    off sensor_latest.json, where the field has never been written
    (zones is always {}).
    Reuse the values the user already enters per zone (setpoint and
    tolerance) to derive alarms on the backend:
    warning when |actual - setpoint| > 1× tolerance
    critical when |actual - setpoint| > 2× tole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
    [WriteSensors.py, server.py]
2026-04-29 feat: calibration page for thermocouples and load cells
    New calibration.html (linked from home.html Tools row) with two
    panels — temperature probes and load cells — that drive four new
    endpoints. No more per-probe SSH/CLI to calibrate.
    Backend:
    - WriteSensors applies a per-zone offset_c (clamped to ±5°C) to TC
    readings, sourced from zone_config.json. Existing tolerance/setpoint
    layout — no new file.
    - HX711 threads now hot-reload tare_offset and calibration_factor
    from scale_config.json on mtime change, so a fresh tare/cal takes
    effect on the running scale without a service restart.
    - write_json now exposes weight_raw_<id> in sensor_latest.json so
    the calibration page can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
    [WriteSensors.py, server.py]
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2026-04-30 feat: room temp card, drop fan-graph from zone modal, default new runs to manual-off
    - Add Room Temp card alongside Humidity and Weight on the home dashboard,
    and reorder so the three quick-view cards sit above the notes (room temp,
    humidity, weight stay visible even when notes get long).
    - Remove the per-zone fan on/off chart from the zone detail modal — modal
    now shows controls (setpoint, tolerance, mode, manual fan, status, notes)
    only.
    - New runs default every zone to a manual "off" override so fans don't
    spin up while the operator is still loading the table.
    [db.py]
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2026-05-01 fix: critical stability fixes for long-running fermentation batches
    1. Backup system was targeting wrong DB file (sake.db → smartsake.db)
    and using raw file copy on WAL-mode SQLite. Now uses sqlite3 online
    backup API for safe, consistent snapshots.
    2. Atomic writes for fan_state.json, zone_config.json, and
    scale_config.json — write to .tmp then os.replace() to prevent
    corruption on power loss.
    3. Removed duplicate sensor loop from server.py — gunicorn workers
    were each spawning their own loop, fighting over GPIO with the
    standalone systemd sensor service.
    4. CSV export now streams rows via generator instead of loading the
    entire run into memory. A 2-week run no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
    [WriteSensors.py, backup_db.py, db.py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]
2026-05-01 fix: medium-severity stability hardening for multi-week runs
    1. Connection pooling: cache one SQLite connection per thread via
    threading.local() — eliminates 6+ connect/pragma cycles per 2s loop.
    2. Memory leak fix: clear _threshold_breach_start and _deviation_tracking
    dicts when active run changes, preventing unbounded growth across runs.
    3. Cap readings API: /api/runs/<id>/readings now defaults to 600 sampled
    points (clamped 1–10000), removing the unbounded fetchall() OOM path.
    4. Consecutive failure alerting: sensor loop counts failures and writes
    sensor_status.json after 15 consecutive errors (30s). Surfaced via
    /api/sensor-status as loop_status.
    5. Disk space moni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
    [WriteSensors.py, db.py, server.py]
2026-05-01 fix: low-severity cleanup — CSV perf, clean shutdown, systemd audit
    1. CSV rotation now tracks line count in memory instead of re-reading
    the entire file every 2 seconds.
    2. Clean shutdown calls db.close_conn() to flush the cached SQLite
    connection on SIGTERM/SIGINT.
    3. Annotated stale systemd units (smartsake-sensors.service,
    smartsake-server.service) as deprecated — canonical is
    smartsake.service.
    [WriteSensors.py]
2026-05-01 fix: remove stale index.html, restore sensor thread, clean up systemd
    1. index.html replaced with redirect to home.html — was a stale copy
    with broken /start_run and /end_run endpoints.
    2. Sensor loop restored in server.py __main__ block — safe for the
    canonical single-process deployment. Gunicorn deployments use the
    standalone smartsake-sensors.service instead.
    3. Backup service updated to canonical kojitable user/paths.
    4. Sensors service updated to canonical paths, kept as gunicorn fallback.
    5. Deleted smartsake-server.service (deprecated gunicorn config).
    [server.py]
2026-05-01 feat(calibration): two-point linear thermocouple calibration
    Replace single-point offset with linear correction (slope * raw + intercept)
    derived from two known reference temperatures (e.g. ice bath + hot water).
    Backward compatible — existing offset_c configs still work as fallback.
    - WriteSensors: _zone_tc_correct() applies slope/intercept or offset_c
    - server.py: new /record-point and /two-point API endpoints
    - calibration.html: step-by-step inline workflow with live preview,
    plus quick-cal option for single-point when only one reference available
    [WriteSensors.py, server.py]
2026-05-01 fix: stability audit — streaming curves, TC filter, query perf, SD wear
    - Stream generate_curve_from_runs via fetchmany (fixes OOM on long runs)
    - Add 5-sample rolling median filter on TC readings before fan logic
    - Replace ROW_NUMBER() sampling with rowid modulo (faster on large tables)
    - Throttle JSON writes to every 3rd cycle (~6s) to reduce SD card wear
    - Widen fan deadband from 3 to 5 cycles (~10s) for relay protection
    - Add connection-lost banner on dashboard when polls fail
    - Add emergency stop button (all fans off) with API endpoint
    - Confirmation dialog on calibration clear and theme reset
    - Backup timer: daily → every 6 hours
    - Enable PRAGMA foreign_keys
    - Remove dead get_all_r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
    [WriteSensors.py, db.py, server.py]
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2026-05-02 fix: stability audit v2 — crash fixes, SD wear reduction, memory leaks
    C1: DB_FILE is now a Path object — prune_for_space() no longer crashes
    C2: delete_run wrapped in BEGIN IMMEDIATE transaction for power-loss safety
    C3: Backup verifies integrity after copy, deletes corrupt backups
    C4: Prune runs before backup so disk-full doesn't block both
    C5: room-history charts created once, data updated in place (no destroy/recreate)
    C6: Visibility guards pause polling when tab is hidden (room-history, calibration)
    H1: HX711 weight log throttled 60x (every 30s vs 0.5s) — saves 680K SD writes/day
    H8: WAL pragma moved to init_db() only (persistent, skip per-connection)
    H13: localStorage saves debou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
    [WriteSensors.py, backup_db.py, db.py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]
2026-05-02 fix: server caching, static file security, query optimization, polling guards
    H2: Mtime-cached JSON file reader — /api/latest no longer re-reads files
    from disk when they haven't changed (hottest endpoint)
    H3: Static file route restricted to safe extensions (.html, .css, .js, etc)
    — blocks access to .py source, .db database, and sensitive configs
    H4: 1-Wire device discovery cached for 2 minutes instead of globbing sysfs
    every 2-second sensor cycle
    H6: ROW_NUMBER() replaced with rowid modulo in get_room_history and
    get_weight_analytics — avoids materializing full result set
    H12: Dashboard visibility guard pauses sensor + fan polling when tab hidden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
    [db.py, sensors.py, server.py]
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
